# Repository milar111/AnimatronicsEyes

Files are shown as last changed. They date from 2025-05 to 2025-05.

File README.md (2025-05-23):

# Animatronic Eyes Project

A servo-controlled animatronic eyes system featuring realistic movements and animations, controlled via Bluetooth gamepad (PS4 controller).

## Overview

This project creates lifelike animatronic eyes using servo motors for X/Y movement and eyelid control, powered by an ESP32 microcontroller and controllable through a Bluetooth gamepad (PS4 controller).

## Features

* Full X/Y axis eye movement control
* Independent left/right eyelid control
* Bluetooth gamepad (PS4 controller) integration
* "Sus mode" animation sequence
* Servo calibration utilities
* 3D printable mechanical components

## Hardware Requirements

* 3D printed components (files provided)
* 1x ESP32 development board
* 1x PCA9685 PWM servo driver
* 4x micro servo motors
* 1x Bluetooth gamepad (PS4 controller)
* 1x power supply
* Wires

## 3D Printing Instructions

### Print Settings
* Layer Height: 0.2mm
* Wall Loops: 2
* Infill: Grid 15%
* Support Type: Tree

### Part Quantities
Parts to print twice (2x):
* Screws:
  * [shortScrewUpperEyeLid.stl](https://github.com/milar111/AnimatronicsEyes/raw/main/3dFiles/shortScrewUpperEyeLid.stl)
  * [longScrewLowerEyeLid.stl](https://github.com/milar111/AnimatronicsEyes/raw/main/3dFiles/longScrewLowerEyeLid.stl)
  * [eyeLidScrew.stl](https://github.com/milar111/AnimatronicsEyes/raw/main/3dFiles/eyeLidScrew.stl)
  * [eye.stl](https://github.com/milar111/AnimatronicsEyes/raw/main/3dFiles/eye.stl)
  * [xAxisArm3.stl](https://github.com/milar111/AnimatronicsEyes/raw/main/3dFiles/xAxisArm3.stl)

Parts to print once (1x):
* Base and Arms:
  * [base.stl](https://github.com/milar111/AnimatronicsEyes/raw/main/3dFiles/base.stl)
  * [xAxisArm1.stl](https://github.com/milar111/AnimatronicsEyes/raw/main/3dFiles/xAxisArm1.stl)
  * [xAxisArm2.stl](https://github.com/milar111/AnimatronicsEyes/raw/main/3dFiles/xAxisArm2.stl)
  * [yAxisArm1.stl](https://github.com/milar111/AnimatronicsEyes/raw/main/3dFiles/yAxisArm1.stl)
  * [yAxisArm2.stl](https://github.com/milar111/AnimatronicsEyes/raw/main/3dFiles/yAxisArm2.stl)
  * [yAxisArm3.stl](https://github.com/milar111/AnimatronicsEyes/raw/main/3dFiles/yAxisArm3.stl)
* Eyelid Components:
  * [upperEyeLidLeft.stl](https://github.com/milar111/AnimatronicsEyes/raw/main/3dFiles/upperEyeLidLeft.stl)
  * [lowerEyeLidLeft.stl](https://github.com/milar111/AnimatronicsEyes/raw/main/3dFiles/lowerEyeLidLeft.stl)
  * [upperEyeLidRight.stl](https://github.com/milar111/AnimatronicsEyes/raw/main/3dFiles/upperEyeLidRight.stl)
  * [lowerEyeLidRight.stl](https://github.com/milar111/AnimatronicsEyes/raw/main/3dFiles/lowerEyeLidRight.stl)
  * [upperArmLeft.stl](https://github.com/milar111/AnimatronicsEyes/raw/main/3dFiles/upperArmLeft.stl)
  * [lowerArmLeft.stl](https://github.com/milar111/AnimatronicsEyes/raw/main/3dFiles/lowerArmLeft.stl)
  * [upperArmRight.stl](https://github.com/milar111/AnimatronicsEyes/raw/main/3dFiles/upperArmRight.stl)
  * [lowerArmRight.stl](https://github.com/milar111/AnimatronicsEyes/raw/main/3dFiles/lowerArmRight.stl)
  * [eyeLidArmLeft.stl](https://github.com/milar111/AnimatronicsEyes/raw/main/3dFiles/eyeLidArmLeft.stl)
  * [eyeLidArmRight.stl](https://github.com/milar111/AnimatronicsEyes/raw/main/3dFiles/eyeLidArmRight.stl)

## Wiring Instructions

Connect ESP32 to PCA9685 (left side pins):

```
ESP32       -> PCA9685
GND         -> GND
GPIO22(SCL) -> SCL
GPIO21(SDA) -> SDA
VCC(on PCA9685 left side) -> V+ (on PCA9685 left side)
```

To power the servos and board:

* Connect the positive wire from the battery to V+ (green terminal block in the middle of PCA9685)
* Connect the negative wire from the battery to V- (other terminal in the green block)

## Servo Channel Mapping

```
Channel 0: Eye X-axis
Channel 1: Eye Y-axis
Channel 2: Left Eyelid
Channel 3: Right Eyelid
```

## Wiring Diagram


## Software Requirements

* Arduino IDE
* Required Libraries:

  * Wire.h
  * Adafruit\_PWMServoDriver
  * Bluepad32

## Setup Guide

1. **Install Software**

   * Install Arduino IDE
   * Add ESP32 board support to Arduino IDE
   * Install required libraries: Adafruit PWM Servo Driver Library, Bluepad32

2. **Initial Hardware Setup**

   * Wire the ESP32 and PCA9685 as described above.

3. **Servo Calibration**

   * Connect the first servo to Channel 0:

     ```
     PCA9685    -> Servo
     V+         -> Red (5V)
     GND        -> Brown (GND)
     Channel 0  -> Orange (Signal)
     ```

   * Upload `servo_calibration.ino` to center all servos at 90° for initial alignment.

4. **Servo Range Test**

   * Upload `angle_tester.ino` and open Serial Monitor (115200 baud).
   * Test each servo channel:

     * Channel 0 (X-axis): Find left/right limits (typically 70°-130°)
     * Channel 1 (Y-axis): Find up/down limits (typically 70°-110°)
     * Channel 2-3 (Eyelids): Test open/close (see below for values)
   * The default values provided below should work for most setups. If you experience issues, use the angle\_tester to determine your own safe ranges and update them in `main.ino`.

5. **Software Configuration**

   * Adjust servo limits in `main.ino` as needed:

     ```cpp
     const int xLeft  = 130;  // Your tested left limit
     const int xRight = 70;   // Your tested right limit
     const int xMid   = 95;   // Your center position

     const int yUp    = 70;   // Your tested up limit
     const int yDown  = 110;  // Your tested down limit
     ```

6. **Final Assembly**

   * \[assembly instructions coming soon]

7. **Final Testing**

   * Upload `main.ino`
   * Pair your Bluetooth gamepad (PS4 controller)
   * Test controls:

     * Left analog stick: Eye X/Y movement
     * L2/R2 triggers: Left/right eyelid control
     * Triangle button: "Sus mode" animation

## Assembly Instructions

1. **Servo Mounting**

   * Mount all servos to the base. Ensure that the yAxisArm1 is connected to the y-axis servo before assembling the left eyelid servo.

     <p>
       
       
     </p>

2. **Arm Connections**

   * Connect all arms to their corresponding servos.

     <p>
       
     </p>

   * Connect both eyes to the base, being careful not to break the flexible but fragile base pins.

     <p>
       
     </p>

   * Connect [xAxisArm3.stl](https://github.com/milar111/AnimatronicsEyes/raw/main/3dFiles/xAxisArm3.stl) to the eyes, then [xAxisArm2.stl](https://github.com/milar111/AnimatronicsEyes/raw/main/3dFiles/xAxisArm2.stl) to [xAxisArm3.stl](https://github.com/milar111/AnimatronicsEyes/raw/main/3dFiles/xAxisArm3.stl). After centering the servos, insert the protruding part of [xAxisArm2.stl](https://github.com/milar111/AnimatronicsEyes/raw/main/3dFiles/xAxisArm2.stl) into the hole in [xAxisArm1.stl](https://github.com/milar111/AnimatronicsEyes/raw/main/3dFiles/xAxisArm1.stl).

     <p>
       
       
       
     </p>

   * Connect [yAxisArm3.stl](https://github.com/milar111/AnimatronicsEyes/raw/main/3dFiles/yAxisArm3.stl) to [yAxisArm2.stl](https://github.com/milar111/AnimatronicsEyes/raw/main/3dFiles/yAxisArm2.stl), then [yAxisArm2.stl](https://github.com/milar111/AnimatronicsEyes/raw/main/3dFiles/yAxisArm2.stl) to [xAxisArm1.stl](https://github.com/milar111/AnimatronicsEyes/raw/main/3dFiles/xAxisArm1.stl) (which should already be connected to the servo). Be cautious as these parts are flexible but can break under tension.

     <p>
       
       
     </p>

3. **Eyelid Assembly**

   * Connect the eyelids to both the left and right eyes. The supporting part is designed to be flexible but can bend or break under excessive tension.
   * Attach the upper and lower arms to the eyelids using the corresponding screws (long screw for the lower eyelid arm, short screw for the upper eyelid arm). First attach the upper arm, then the lower arm.
   * For easier assembly, first attach the arms to the eyelids, then connect them to the base.
   * Connect the [eyeLidArmLeft.stl](https://github.com/milar111/AnimatronicsEyes/raw/main/3dFiles/eyeLidArmLeft.stl) and [eyeLidArmRight.stl](https://github.com/milar111/AnimatronicsEyes/raw/main/3dFiles/eyeLidArmRight.stl) to the eyelid arms using the [eyeLidScrew.stl](https://github.com/milar111/AnimatronicsEyes/raw/main/3dFiles/eyeLidScrew.stl).

     <p>
       
       
       
     </p>

4. **Eyelid Servo Calibration**

   * **Important Note:** The arm/horn mounted on the eyelid servo should not be perpendicular to the servo itself.
   * **Calibration Steps:**

     * Ensure all servos are calibrated to 90 degrees using `servo_calibration.ino`.
     * Close both eyelids.
     * Mount the arm on the servo (eyelidarmleft/right) and slide it until the eyelids are closed. This should not move the motor; if it does, recalibrate the servo.
     * Repeat the process for the other eye.

### 5. **Final Adjustments**

* The assembly is designed for a tight, snap-fit connection. Only the x and y axis arms require screws for the horns.
* Ensure all connections are secure and the mechanism moves smoothly without additional parts.

<div style="display: flex; justify-content: space-between;">
  
  
</div>

### 6. **Additional Resources**

* I found these doll eyes on AliExpress that fit perfectly into the [eye.stl](https://github.com/milar111/AnimatronicsEyes/raw/main/3dFiles/eye.stl) file: [Doll Eyes on AliExpress](https://a.aliexpress.com/_EHM9l0K)

---

## Troubleshooting

### Servo Issues

* **Jittering:** Check power supply (2A minimum)
* **Binding:** Verify servo limits
* **Unresponsive:** Check wiring connections

### Control Issues

* **No gamepad (PS4 controller) response:** Check battery/pairing
* **Erratic movement:** Verify servo limits
* **Strange behavior:** Check channel assignments

---

## Reference Values

### Default Servo Ranges

```
X-axis: 70° to 130° (center: 95°)
Y-axis: 70° to 110° (center: 90°)
Eyelids: Left: 50° (closed) to 90° (open)
         Right: 50° (open) to 90° (closed)
```

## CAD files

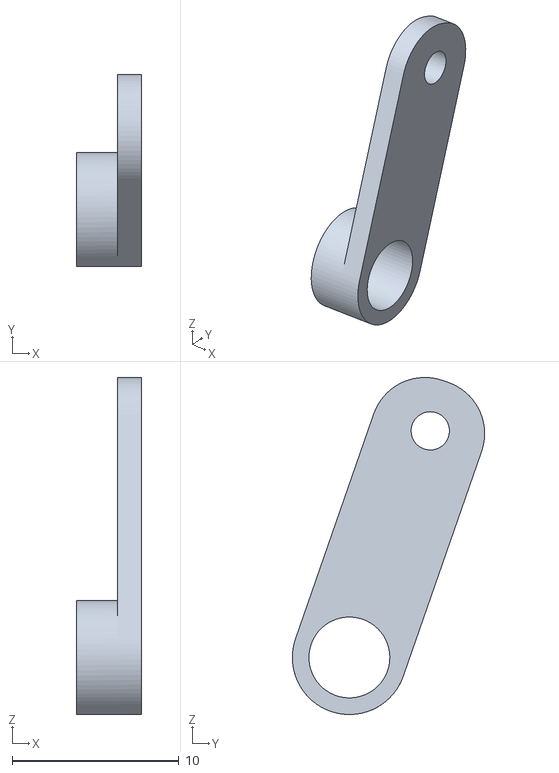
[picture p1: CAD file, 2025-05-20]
3dFiles/eyeLidArmRight.stl
3.90 x 11.5 x 20.2

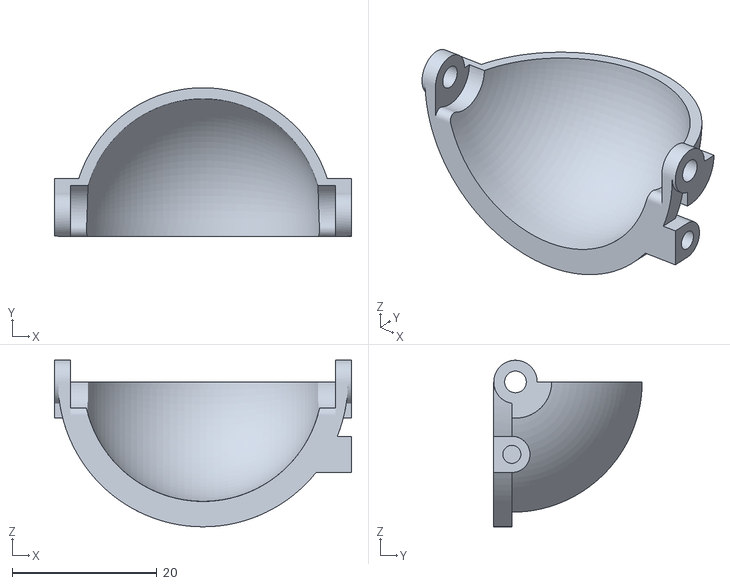
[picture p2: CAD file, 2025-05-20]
3dFiles/upperEyeLidLeft.stl
41.0 x 20.5 x 23.0

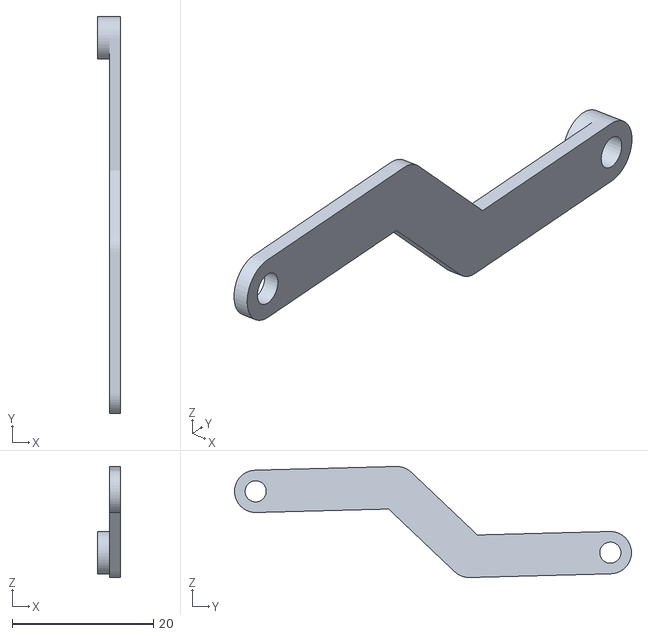
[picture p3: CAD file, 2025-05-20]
3dFiles/lowerArmRight.stl
3.20 x 56.2 x 15.7

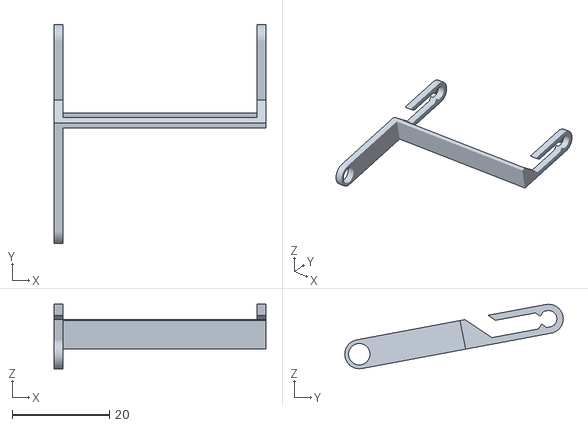
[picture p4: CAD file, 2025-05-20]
3dFiles/yAxisArm2.stl
43.6 x 45.0 x 13.3

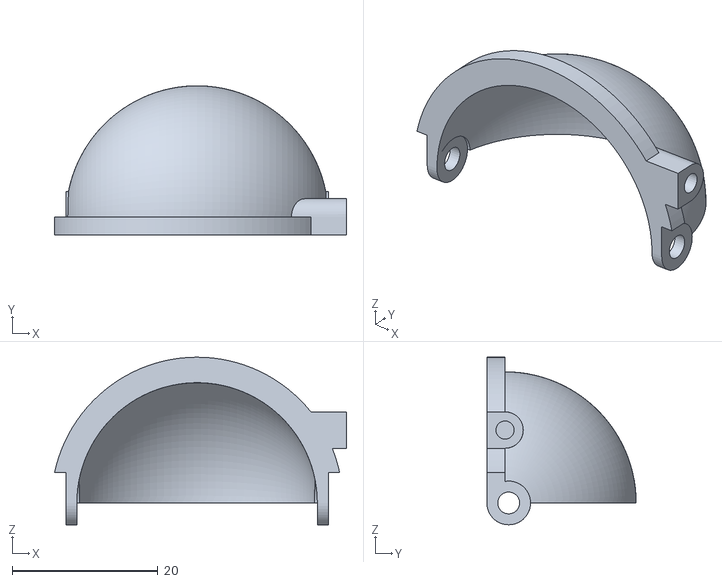
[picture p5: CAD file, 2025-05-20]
3dFiles/lowerEyeLidLeft.stl
40.1 x 20.5 x 23.0

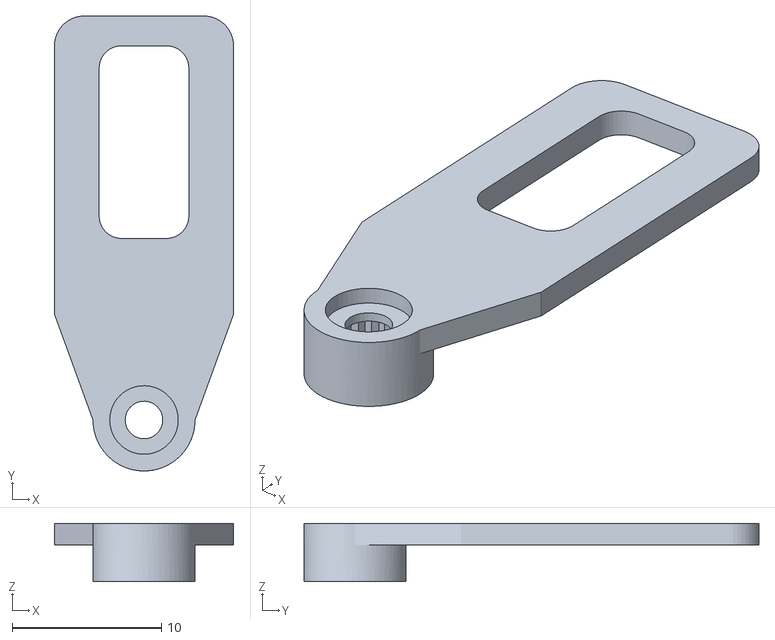
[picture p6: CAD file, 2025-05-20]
3dFiles/xAxisArm1.stl
12.0 x 30.5 x 3.90

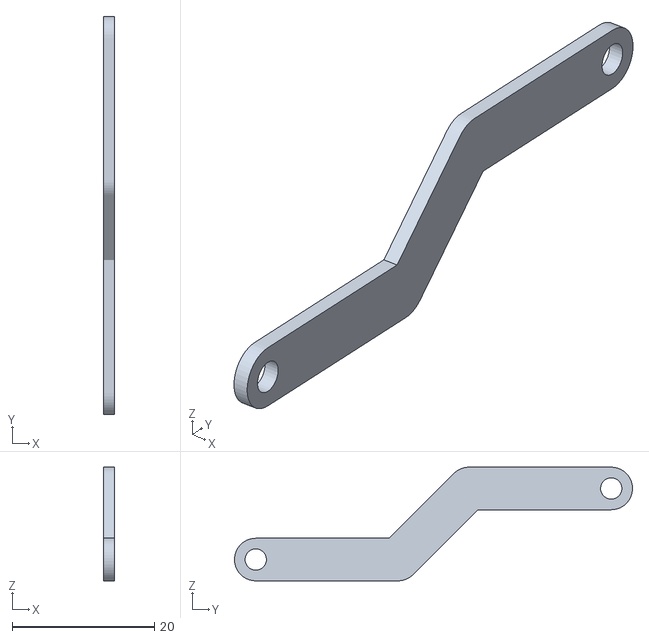
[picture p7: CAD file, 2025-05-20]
3dFiles/upperArmRight.stl
1.50 x 56.0 x 16.0

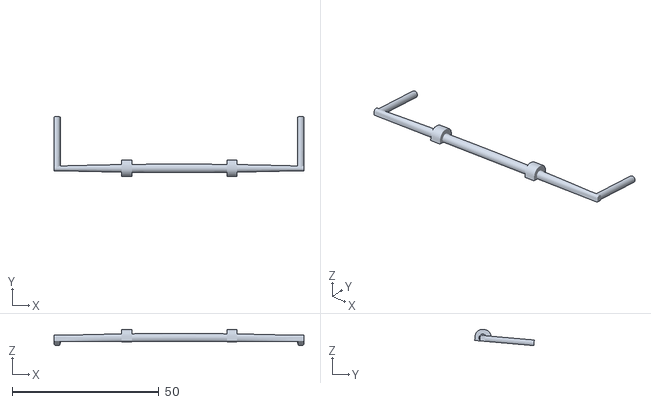
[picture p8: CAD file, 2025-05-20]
3dFiles/yAxisArm3.stl
85.2 x 20.3 x 5.53

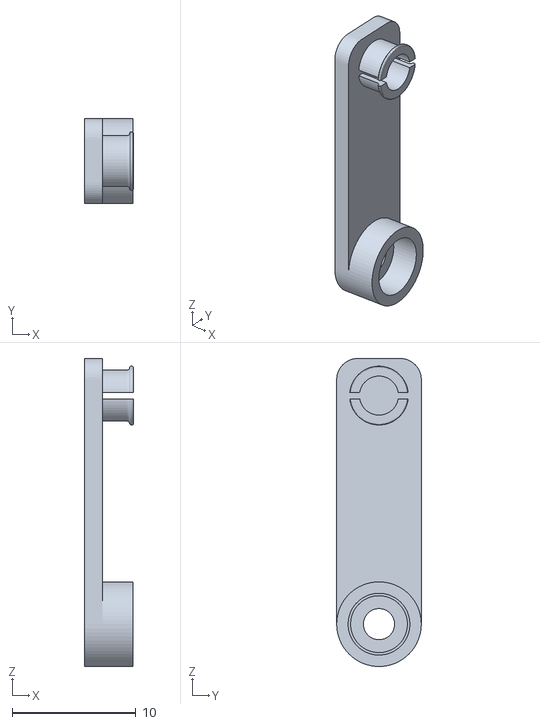
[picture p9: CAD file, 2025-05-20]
3dFiles/yAxisArm1.stl
3.95 x 6.85 x 24.9

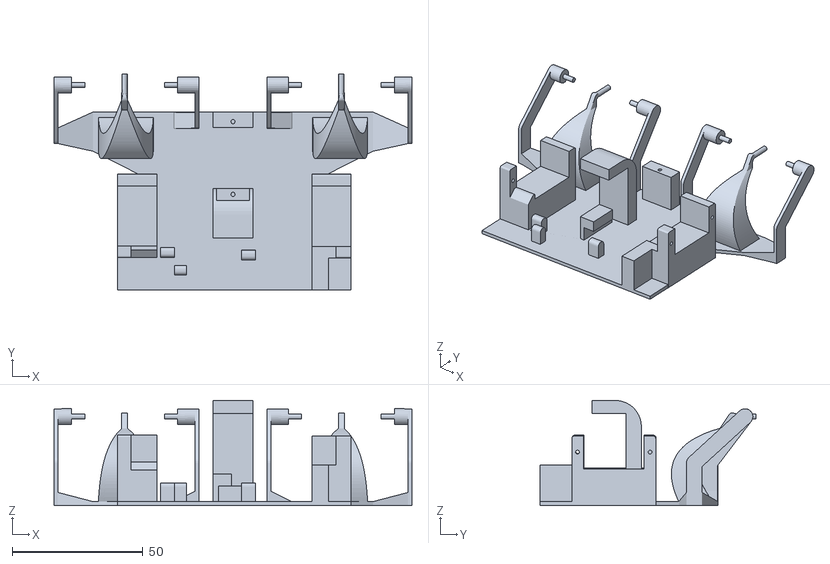
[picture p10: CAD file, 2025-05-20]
3dFiles/base.stl
137.0 x 82.7 x 40.2

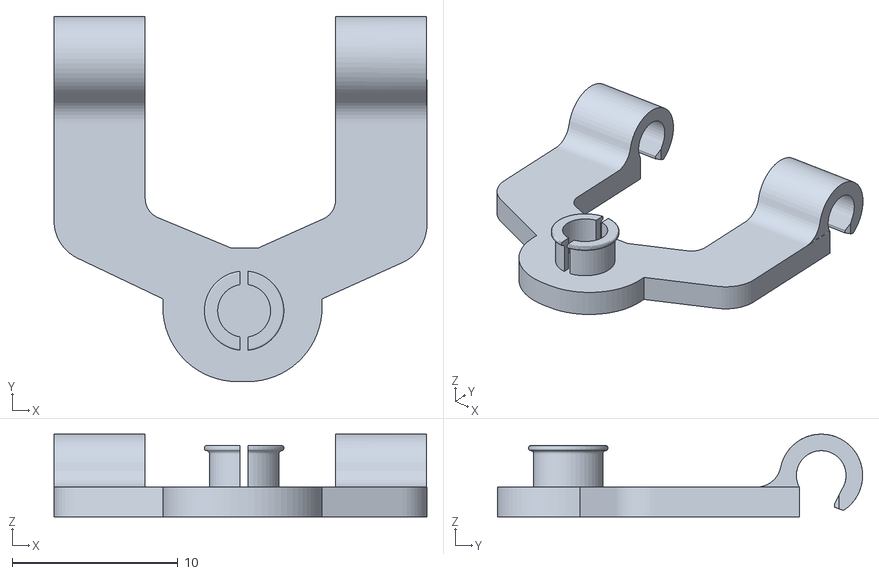
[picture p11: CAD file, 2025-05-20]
3dFiles/xAxisArm3.stl
22.5 x 22.1 x 5.00

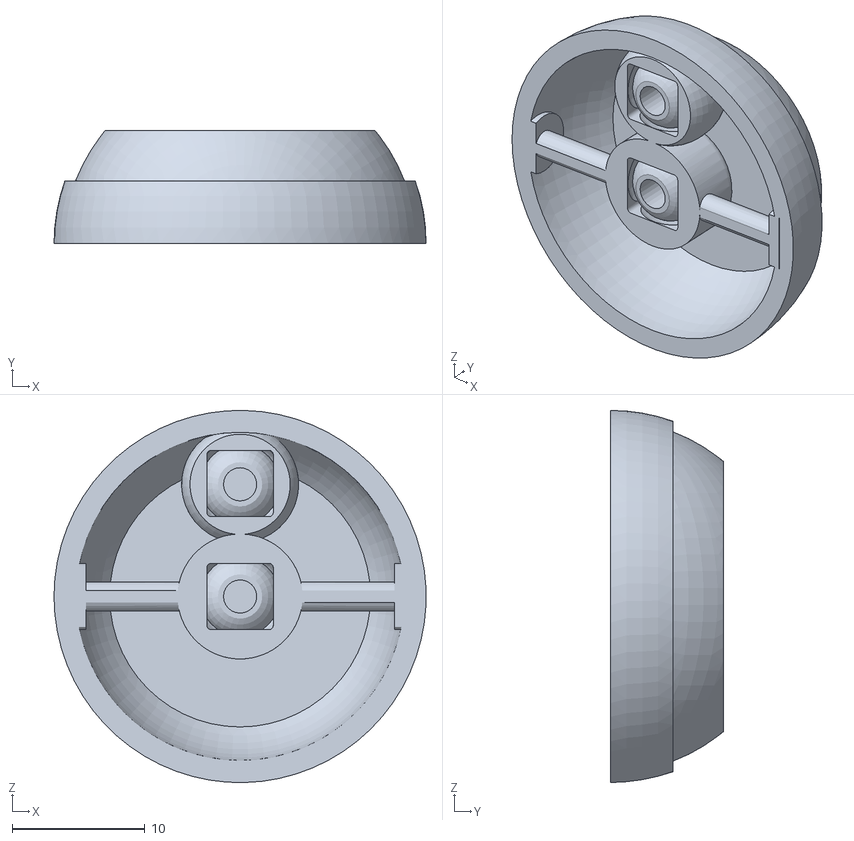
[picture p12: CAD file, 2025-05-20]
3dFiles/eye.stl
28.0 x 8.50 x 28.0

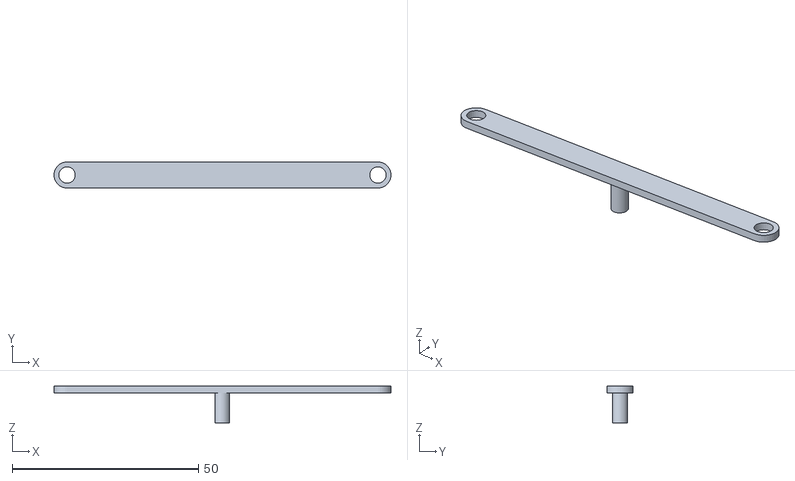
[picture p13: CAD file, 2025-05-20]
3dFiles/xAxisArm2.stl
90.4 x 7.00 x 9.80

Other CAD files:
3dFiles/lowerEyeLidRight.stl
3dFiles/upperArmLeft.stl
3dFiles/upperEyeLidRight.stl
3dFiles/eyeLidArmLeft.stl
3dFiles/lowerArmLeft.stl
3dFiles/eyeLidScrew.stl
3dFiles/longScrewLowerEyeLid.stl
3dFiles/shortScrewUpperEyeLid.stl

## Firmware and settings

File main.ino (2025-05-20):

#include <Wire.h>
#include <Adafruit_PWMServoDriver.h>
#include <Bluepad32.h>

Adafruit_PWMServoDriver pwm;

// Eye limits and mid‑points
const int xLeft  = 130;
const int xRight =  70;
const int xMid   =  95;

const int yUp    =  70;
const int yDown  = 110;
const int yMid   = (yUp + yDown) / 2;  // 90

// radius
const int RADIUS = min(
  min(abs(xLeft - xMid), abs(xMid - xRight)),
  min(abs(yMid - yUp),    abs(yDown - yMid))
); // =20

// Servo channels
#define EYE_X     0
#define EYE_Y     1
#define LID_LEFT  2
#define LID_RIGHT 3

#define SERVO_MIN 102
#define SERVO_MAX 512

ControllerPtr controllers[BP32_MAX_GAMEPADS];

// animation state machine
bool susActive    = false;
int  sweepDir     = +1;   // +1 = left=>right, –1 = right=>left
int  passesLeft   = 0;
unsigned long stateStart = 0;
enum SusState { IDLE, PAUSE_END, CENTER_HOLD, SWEEP } susState = IDLE;

void onConnectedController(ControllerPtr ctl) {
  for (int i = 0; i < BP32_MAX_GAMEPADS; i++) {
    if (!controllers[i]) {
      controllers[i] = ctl;
      break;
    }
  }
}

void onDisconnectedController(ControllerPtr ctl) {
  for (int i = 0; i < BP32_MAX_GAMEPADS; i++) {
    if (controllers[i] == ctl) {
      controllers[i] = nullptr;
      break;
    }
  }
}

void setServo(int ch, int angle) {
  angle = constrain(angle, 0, 180);
  uint16_t pulse = map(angle, 0, 180, SERVO_MIN, SERVO_MAX);
  pwm.setPWM(ch, 0, pulse);
}

void setup() {
  Serial.begin(115200);
  Wire.begin();
  pwm.begin();
  pwm.setPWMFreq(50);
  delay(200);

  // center eyes, open lids
  setServo(EYE_X, xMid);
  setServo(EYE_Y, yMid);
  setServo(LID_LEFT,  50);
  setServo(LID_RIGHT, 90);

  BP32.setup(&onConnectedController, &onDisconnectedController);
  BP32.forgetBluetoothKeys();
}

void loop() {
  BP32.update();

  // detect triangle hold
  bool tri = false;
  for (auto ctl : controllers) {
    if (ctl && ctl->isConnected()) {
      tri = ctl->y();
      break;
    }
  }

  // enter/exit animation
  if (tri && !susActive) {
    susActive  = true;
    passesLeft = random(3,5);
    sweepDir   = +1;
    susState   = PAUSE_END;
    stateStart = millis();
  } else if (!tri && susActive) {
    susActive = false;
    susState  = IDLE;
    setServo(EYE_X, xMid);
    setServo(EYE_Y, yMid);
    setServo(LID_LEFT,  50);
    setServo(LID_RIGHT, 90);
  }

  if (susActive) {
    unsigned long dt = millis() - stateStart;

    switch (susState) {
      case PAUSE_END:
        setServo(EYE_X, sweepDir>0 ? xLeft : xRight);
        setServo(EYE_Y, yMid);
        setServo(LID_LEFT,  70);
        setServo(LID_RIGHT, 70);
        if (dt > 800) {
          susState   = SWEEP;
          stateStart = millis();
        }
        break;

      case SWEEP: {
        float frac = float(dt) / 5000.0f;
        if (frac > 1) frac = 1;
        int angleX = (sweepDir>0)
          ? xLeft  + round(frac * (xRight - xLeft))
          : xRight + round(frac * (xLeft  - xRight));
        setServo(EYE_X, angleX);
        setServo(EYE_Y, yMid);

        if (dt >= 5000) {
          sweepDir *= -1;
          passesLeft--;
          susState   = (passesLeft>0) ? PAUSE_END : CENTER_HOLD;
          stateStart = millis();
        }
        break;
      }

      case CENTER_HOLD:
        setServo(EYE_X, xMid);
        setServo(EYE_Y, yMid);
        setServo(LID_LEFT,  60);
        setServo(LID_RIGHT, 60);
        if (dt > 1500) {
          // restart
          passesLeft = random(2,3);
          sweepDir   = +1;
          susState   = PAUSE_END;
          stateStart = millis();
        }
        break;

      default:
      case IDLE:
        break;
    }
  }
  else {
    for (auto ctl : controllers) {
      if (!ctl || !ctl->isConnected()) continue;

      float jx = ctl->axisX() / 512.0f;
      float jy = ctl->axisY() / 512.0f;
      const float DZ = 0.10f;
      if (fabs(jx) < DZ) jx = 0;
      if (fabs(jy) < DZ) jy = 0;
      float mag = sqrt(jx*jx + jy*jy);
      if (mag > 1.0f) { jx /= mag; jy /= mag; }

      int angleX = xMid + round(jx * RADIUS);
      int angleY = yMid - round(jy * RADIUS);

      setServo(EYE_X, angleX);
      setServo(EYE_Y, angleY);
      setServo(LID_LEFT,  ctl->throttle() > 0 ? 90 : 50);
      setServo(LID_RIGHT, ctl->brake()    > 0 ? 50 : 90);
      break;
    }
  }
}

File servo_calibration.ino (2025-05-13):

#include <Wire.h>
#include <Adafruit_PWMServoDriver.h>

Adafruit_PWMServoDriver pwm = Adafruit_PWMServoDriver();

#define SERVO_MIN 102
#define SERVO_MAX 512

#define SERVO_CENTER map(90, 0, 180, SERVO_MIN, SERVO_MAX)

#define SERVO_1 0
#define SERVO_2 1
#define SERVO_3 2
#define SERVO_4 3

void setup() {
  Serial.begin(115200);
  Wire.begin();
  pwm.begin();
  pwm.setPWMFreq(50);  

  delay(500);
  uint16_t pulse = SERVO_CENTER;
  Serial.print("Centering servos to pulse: "); Serial.println(pulse);

  pwm.setPWM(SERVO_1, 0, pulse);
  pwm.setPWM(SERVO_2, 0, pulse);
  pwm.setPWM(SERVO_3, 0, pulse);
  pwm.setPWM(SERVO_4, 0, pulse);
}

void loop() {
}
SSS

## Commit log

2025-05-03 x and y axis movement over bluetooth(dpad)
2025-05-20 STL files added
    [base.stl, eye.stl, eyeLidArmLeft.stl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]
2025-05-20 Assembly Instructions
2025-05-23 wiring diagram added
